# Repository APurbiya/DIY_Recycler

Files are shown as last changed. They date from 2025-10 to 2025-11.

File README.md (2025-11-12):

<p align="center">
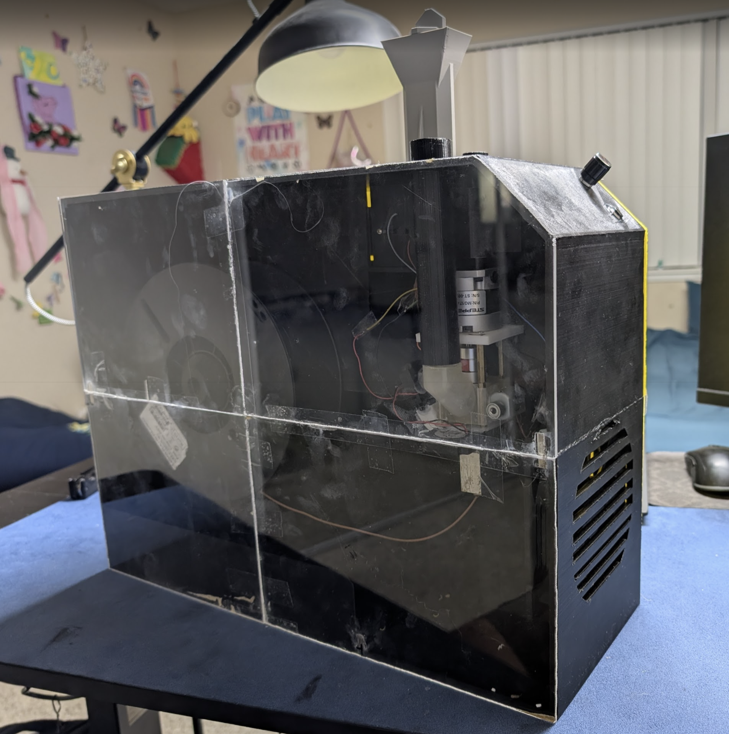
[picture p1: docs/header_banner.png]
Bambu Poop Recycler Banner
  
</p>
# ♻️ Bambu Poop Recycler – Desktop Filament Extruder

Converting **Bambu Poop** (failed prints / support waste) back into **usable filament** using a **screw-based extruder**.  
The goal: a **compact, desktop-friendly recycler** that handles the entire process — **shredding → extruding → spooling** — all from one enclosure.

---

## 📚 Table of Contents

- [🧩 System Overview](#-system-overview)
- [⚡️ Power Distribution](#️-power-distribution)
- [🧵 RAMPS 1.4 Wiring Guide](#-ramps-14-wiring-guide)
- [⚙️ 12 V PSU → Component Wiring](#️-12-v-psu--component-wiring)
- [🪛 Assembly Tips](#-assembly-tips)
- [🧯 Power Safety](#-power-safety)
- [🤖 3D Printing Guide](#-3d-printing-guide)
- [🧰 Assembly](#-assembly)
  - [🔩 Extruder Assembly](#-extruder-assembly)
  - [⚙️ Shredder Assembly](#️-shredder-assembly)
  - [🧱 Main Housing Assembly](#-main-housing-assembly)
  - [🎞️ Spooler Assembly](#-spooler-assembly)
  - [🧩 Final Integration](#-final-integration)

---

## 🧩 System Overview

| Component | Function |
|---|---|
| **Arduino Mega + RAMPS 1.4** | Controls heater, thermistor, fans, vibrator, and 2 stepper drivers (extruder screw + spooler). |
| **Drill Motor + Motor Controller (e.g., DC PWM driver)** | Drives shredder or auger screw for initial granulation. |
| **12 V PSU (≥ 20 A)** | Main power source for heaters, fans, steppers, and motor controller. |
| **Buck Converter (12 V → 5 V)** | Powers ESP32 dashboard and 5 V logic fans. |
| **ESP32** | Monitors Mega’s serial output and serves real-time data on a local webpage. |

---

## ⚡️ Power Distribution

| Source | Destination | Description |
|---|---|---|
| **12 V DC PSU (20 A min)** | **RAMPS 1.4 (11 A + 5 A inputs)** | Main power for heater, fans, and steppers |
|  | **DC Motor Controller (for drill motor)** | Supplies high-current 12 V for shredding/auger motor |
|  | **Buck Converter (input)** | Feeds 12 V into buck regulator |
|  | → **5 V Output (from Buck Converter)** | Powers ESP32 + 5 V logic fans |
| **Ground (GND)** | All components common | Connect PSU GND ↔ RAMPS GND ↔ Buck GND ↔ Motor Controller GND ↔ ESP32 GND |

✅ **Tip:** all grounds **must** be common (PSU GND ↔ RAMPS GND ↔ Buck GND ↔ Motor Controller GND ↔ ESP32 GND).

---

## 🧵 RAMPS 1.4 Wiring Guide

| Function | RAMPS Pins | Connected Component | Notes |
|---|---|---|---|
| **Heater** | D10 | Extruder heater cartridge | MOSFET output, 12 V |
| **Thermistor (T0)** | T0 (A13) | 100 k NTC thermistor | Connect one leg to T0, one to GND |
| **Stepper A (E0)** | X-driver socket (A_STEP=54, A_DIR=55, A_EN=38) | Extruder stepper | Drives screw |
| **Stepper B (E1)** | Y-driver socket (B_STEP=60, B_DIR=61, B_EN=56) | Spooler stepper | Controls filament winding |
| **Fans (12 V)** | D9 (PWM MOSFET) | 12 V cooling fan | Variable speed based on temp/activity |
| **Fans (5 V)** | D4, D6 | Small logic fans | Driven via MOSFET or transistor boards |
| **Vibrator / Mixer Motor** | D16/D17/D5 → L298N IN1/IN2/ENA | Vibrating base / mixer | PWM controlled |
| **Heat Toggle Button** | A15 | Momentary push button → GND | Toggles heating cycle |
| **Encoder** | D31 (CLK), D33 (DT), D35 (SW) | Rotary encoder | Speed + direction control |
| **ESP32 Link** | TX0 (pin 1) → RX (via 1 k/2 k divider) | ESP32 RX pin | Sends data for web dashboard |
| | RX0 (pin 0) ← TX (3.3 V) | ESP32 TX pin | Optional (disconnect when uploading) |

---

## ⚙️ 12 V PSU → Component Wiring

| Output | Destination | Wire Gauge | Notes |
|---|---|---|---|
| +12 V | RAMPS Power Inputs (11 A & 5 A) | 14–16 AWG | Use ferrules or ring terminals |
| +12 V | Drill Motor Controller V+ | 14 AWG | Feeds high-current DC motor |
| +12 V | Buck Converter IN+ | 18 AWG | For ESP32 + 5 V logic |
| GND | Common to all | 14–18 AWG | Must tie all GNDs together |

### Buck Converter
| Input | Output | Use |
|---|---|-----|
| 12 V IN + / – | 5 V OUT + / – | Powers ESP32, small 5 V fans and L298N |

### Drill Motor Controller
| Input | Output | Use |
|---|---|-----|
| +12 V / GND | M+ / M– | Connects to drill/auger motor |
| PWM / POT / CTRL | Optional | Speed control (manual or logic-level) |

---

## 🪛 Assembly Tips

- **Full assembly guide will me added SOON**
- Keep **heater + thermistor wires** away from **motor leads** to avoid noise.
- Mount the **buck converter** near the ESP32; keep its output wires short.
- Label all 12 V lines before final crimping.
- Always test the **heater MOSFET** and **fan MOSFETs** with a multimeter before loading filament.
- Add a **thermal fuse (250 °C)** inline with the heater block for safety.

---

## 🧯 Power Safety

- Use a **12 V 20 A (240 W) PSU** with built-in short-circuit protection.
- Add a **5 A inline fuse** for the RAMPS input and **10 A fuse** for the motor controller branch.
- Ensure metal enclosures are **earth-grounded**.
- Never leave the extruder unattended while heating.

---
## 🤖 3D Printing Guide

- **Extruder**
  - `extruder - chute.step` *(PLA or Resin)*
  - `extruder - pipe.step` *(PLA)*
  - `fan mount - Part 1.step` *(Resin)*
  - `extruder Copy 1 - Part 1.step` *(PLA or Resin)*
  - `extruder Copy 1 - Part 2.step` *(High Temp Resin)*
  - `extruder Copy 1 - Part 3.step` *(High Temp Resin)*

- **Spooler**
  - `main - Spur gear (170 teeth).step` *(PLA)*
  - `main - Spur gear (30 teeth).step` *(PLA)*
  - `spooler - Part 1.step` *(PLA)*

- **Shredder**
  - `spooler - Part 1.step` *(PLA, 4–5 wall loops recommended)*

- **Main (All PLA)**
  - `main - Motor.step`
  - `main - Part 1.step`
  - `main - Part 4.step`
  - `main - Part 6.step` *(1/4 of Part 1)*
  - `main - Part 7.step` *(2/4 of Part 1)*
  - `main - Part 8.step` *(3/4 of Part 1)*
  - `main - Part 9.step` *(4/4 of Part 1)*
  - `main - motor-holder.step` *(for spooler)*

---

## 🧰 Assembly

This section provides a step-by-step **assembly guide for the entire Bambu Poop Recycler**, broken down into key modules — **Extruder**, **Spooler**, **Shredder**, and **Main Frame**.  
Each subsection includes detailed instructions, part references, and visuals to help you build, wire, and align every component of the system.

Before starting:
- Make sure all 3D-printed and mechanical parts are **cleaned, deburred, and test-fitted**.
- Keep **thread locker, M3/M4 hardware**, and a **soldering iron or crimping tools** nearby.
- Follow the wiring and safety guidelines in earlier sections before powering the system.

---

### 🔩 Extruder Assembly

1. **Attach the Stepper Motor and Planetary Gearbox**  
   Grab your **NEMA stepper motor** and **planetary gearbox**.  
   Use **four M3 screws** to fasten them together as shown in the image below.  

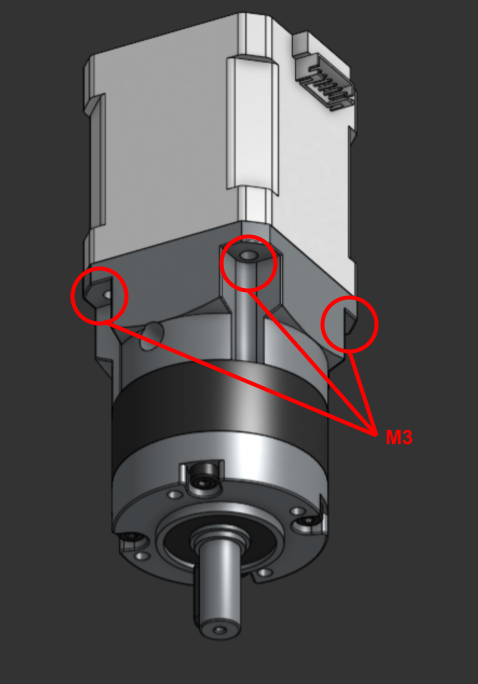
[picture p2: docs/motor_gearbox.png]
Motor + Gearbox Assembly
     
   *Figure 1: Stepper motor and planetary gearbox mounted together.*

---

2. **Mount the 3D-Printed Plate**  
   Secure the **3D-printed plate** to the **planetary gearbox** using **M4 screws** as shown below.  

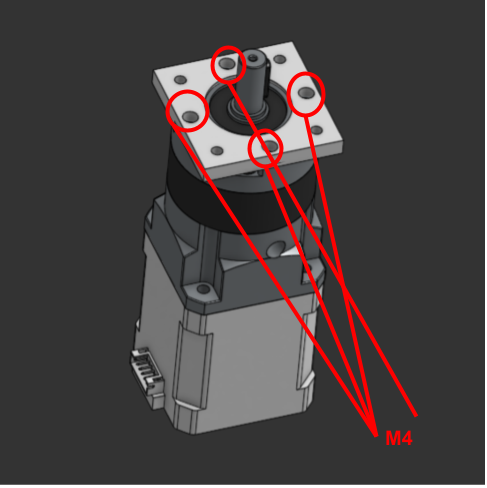
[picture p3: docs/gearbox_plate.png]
Gearbox Mounting Plate
     
   *Figure 2: 3D-printed plate mounted to the gearbox.*

---

3. **Install the Extension Rods**  
   Screw in **four M3 threaded extension rods** (each **57 mm long**) into the plate.  
   Make sure all rods are evenly tightened and parallel.  

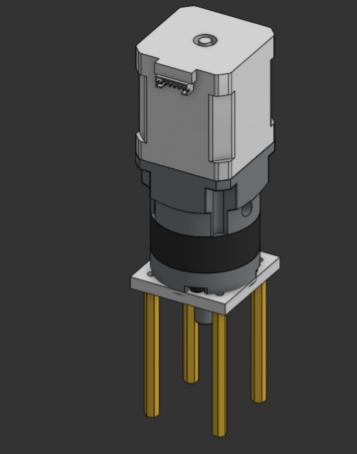
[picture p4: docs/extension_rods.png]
Extension Rods Installation
     
   *Figure 3: Four M4 rods installed on the plate.*

---

4. **Attach the Chute and Resin Plates**  
   Slide the **chute** into the **M3 extension holes** and align it with the bottom side of the assembly.  
   Then attach the **two resin-printed plates** using **M3 screws**.  
   It’s recommended to print these two plates using a **high-temperature material** (e.g., ABS, ASA, or PA-CF).  

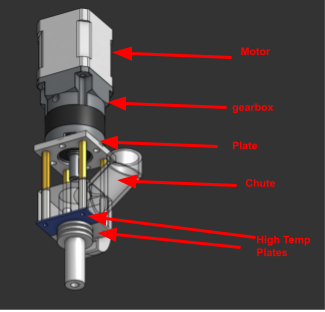
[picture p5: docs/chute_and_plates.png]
Chute and Resin Plates
     
   *Figure 4: Chute inserted and resin plates secured.*

---

5. **Install Cooling and Vibration Components**  
   Hot glue the **fans** and **vent channels** onto the sides of the chute,  
   and attach the **vibration motor** to one side as shown below.  

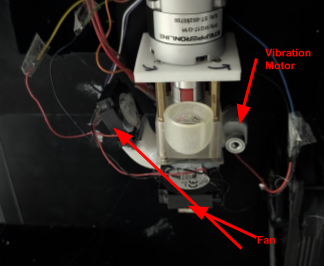
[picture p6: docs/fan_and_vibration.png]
Fans and Vibration Motor Installation
     
   *Figure 5: Fan and vibration motor placement.*

---

6. **Final Extruder Assembly Overview**  
   This is what the completed extruder assembly should look like:  

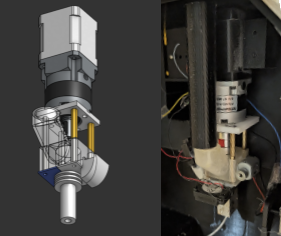
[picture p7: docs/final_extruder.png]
Complete Extruder Assembly
     
   *Figure 6: Final assembled extruder module.*

---

🧠 **Tips:**
- Use **thread locker (Loctite Blue)** on all metal-to-metal threads.
- Ensure the **gearbox output shaft** rotates freely before connecting the screw.
- Keep **fans oriented** to blow across the chute for optimal cooling.
- Route wiring away from the heater and moving parts.

---

### ⚙️ Shredder Assembly

1. **Prepare the Shredder Blade**  
   Cut a **metal ruler** to the correct length so it fits snugly inside the **3D-printed shredder housing**.  
   Make sure both ends are cleanly trimmed and free of burrs before assembly.  

---

2. **Install the Router Bit**  
   Insert the **router bit** into the side hole of the shredder assembly.  
   Slide it in carefully until it seats fully, then **tighten the drill chuck** to secure it in place.  

---

3. **Attach the Motor Mount**  
   Use the **shredder motor mount** to align the drill motor with the printed housing.  
   Do not glue or bolt it permanently yet — this will later **slide into the main frame** during final assembly.  

---

4. **Final Shredder Assembly Overview**  
   The completed shredder module should look similar to the image below.  
   Ensure the **ruler blade**, **router bit**, and **motor mount** all align properly within the printed frame.  

   Final Shredder Assembly  
   *Figure 4: Completed shredder assembly.*

---

🧠 **Tip:**
- Double-check that the **router bit spins freely** without wobble before powering it.   

---

### 🧱 Main Housing Assembly

1. **Align the Printed Sections**  
   Gather all **four 3D-printed housing parts**.  
   Lay them out in order — start with the **top-left section**, followed by the **top-right**, then move **downward** as shown in the reference image.  
   Ensure the edges are clean and fit together tightly before gluing.

---

2. **Bond the Housing Sections**  
   Apply **super glue or CA glue** along the connecting seams.  
   Begin by gluing the **top-left section**, then move to the **right side**, and finally **assemble the lower sections**.  
   Make sure each joint is aligned properly before the glue sets.

---

3. **Final Main Housing Overview**  
   Once assembled, check that the full frame sits flat and square.  
   The **shredder** and **extruder modules** will later slide into this housing frame during final assembly.

   Completed Main Housing  
   *Figure 3: Completed main housing ready for module installation.*

---

🧠 **Tips:**
- Lightly sand the joint surfaces before gluing for stronger adhesion.  
- Use **clamps** or **tape** to hold parts in place while the glue cures.  

---

### 🎞️ Spooler Assembly

1. **Insert the Spur Gear**  
   Take the **large spur gear** and insert it **from the back side of the main housing**.  
   Make sure the gear teeth are facing inward and mesh smoothly with the drive gear inside the housing.  
   Rotate it by hand to confirm it spins freely without binding.
---

2. **Attach the Spooler Module**  
   Align the **spooler part** with the front opening of the housing.  
   Gently **press or clip** it into place — it should hold firmly without glue.  
   If you prefer a more permanent connection, you can add a **small drop of super glue** at each corner.

---

3. **Check Alignment and Rotation**  
   Once installed, ensure the spooler gear and main gear rotate smoothly together.  
   The spool should sit centered and spin freely without wobble.

   Final Spooler Assembly  
   *Figure 3: Completed spooler assembly mounted to the main housing.*

---

🧠 **Tip:**
- If rotation feels stiff, lightly **sand the inner gear edges** or apply a **drop of PTFE lubricant**.  

---

### 🧩 Final Integration

1. **Insert the Shredder Assembly**  
   Slide the **shredder assembly** in **from the back side** of the main housing.  
   Align it carefully with the **top opening** so that the chute and blade section fit into their designated slots.  
   Make sure the motor mount sits flush and the assembly can move slightly for final alignment.

   Insert Shredder Assembly  
   *Figure 1: Shredder assembly slid into position from the back.*

---

2. **Install the Extruder Assembly**  
   Next, slide the **extruder assembly** into the front section of the housing.  
   The **stepper motor** should snap or slide into the **mounting clip** integrated into the frame.  
   Double-check that the extruder chute aligns with the shredder output path for smooth material flow.

   Install Extruder Assembly  
   *Figure 2: Extruder assembly clipped into the front stepper mount.*

---

3. **Verify Module Alignment**  
   With both assemblies in place, check that:
   - The **shredder outlet** aligns directly above the ** hole**.  
   - The **wiring paths** are clear and not pinched between parts.  
   - The **motor shafts** rotate freely without resistance.  

---

🧠 **Tips:** 
- If fitment feels tight, lightly sand the mounting clips or interior guides.  

---

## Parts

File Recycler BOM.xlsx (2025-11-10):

Item | Link | Link 2 | Unit(s) | Unit Price | Total cost
Extruder
Pellet Extruder | https://www.aliexpress.us/item/3256809312197411.html | https://www.amazon.com/Pellet-Extruder-Feeding-Printer-Accessory/dp/B0CF2SF23Q/ | 1 | $87.79 | $87.79
Stepper Motor | https://www.amazon.com/STEPPERONLINE-Stepper-Bipolar-Connector-compatible/dp/B00PNEQKC0 |  | 2 | $13.99 | $27.98 | Total | $337.30
10:1 Reduction | https://www.amazon.com/STEPPERONLINE-STEPPERONLINE-Planetary-Gearbox-Gear-Ratio-5-1-Backlash-30-arc-min-for-9-5mm-Short-Shaft-Length-Nema-17-Stepper-Motor/dp/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 |  | 1 | $24.00 | $24.00
Heater | https://www.amazon.com/ENOMAKER-Ceramic-Cartridge-Thermistor-Creality/dp/B07K2Z3YW4 |  | 1 | $9.45 | $9.45
Nozzel | https://www.amazon.com/Aokin-Extruder-Nozzles-Printer-Filament/dp/B0BLW918YV/ |  | 1 | $5.79 | $5.79
12v fan | https://www.amazon.com/Kingwin-120mm-Silent-Coolers-Mining/dp/B002YFP8BK |  | 1 | $6.69 | $6.69
5v Fan | https://www.amazon.com/Printer-Micro-Brushless-Cooling-Ventilation/dp/B0DY6GQMJX |  | 2 | $3.00 | $5.99
Shredder
Router Bit | https://www.amazon.com/gp/aw/d/B07WW39K4N?psc=1&ref=ppx_pop_mob_b_asin_title |  | 1 | $14.99 | $14.99
drill | https://www.harborfreight.com/12v-cordless-38-in-drill-kit-with-battery-and-charger-57366.html (http://amazon.com/%E2%80%8C12V-775-DC-Motor-Built/dp/B0BW73LMP7) | for shredder | 1 | $19.90 | $19.90
Control Electronics
PSU | https://www.amazon.com/Taormey-Switching-Converter-Transformer-Industrial/dp/B0DP99NVM7/ |  | 1 | $19.39 | $19.39
RAMP 1.4 | https://www.amazon.com/HiLetgo-Control-Printer-Support-Arduino/dp/B06XZ46PDJ |  | 1 | $9.39 | $9.39
Arduino Mega | https://www.amazon.com/ELEGOO-ATmega2560-ATMEGA16U2-Arduino-Compliant/dp/B01H4ZDYCE |  | 1 | $22.99 | $22.99
Buck Converter | https://www.amazon.com/Converter-3-2V-35V-DC1-25V-30V-Voltage-Regulator/dp/B0D7ZWVSFW |  | 1 | $4.99 | $4.99
Motor Driver | https://www.amazon.com/Controller-Driver-Module-Current-Regulator/dp/B075FR2LBP | for shredder | 1 | $10.41 | $10.41
Button | https://www.amazon.com/dp/B0B8Z14K3T/ref=twister_B0CP3QH4PC?_encoding=UTF8&th=1 |  | 2 | $1.60 | $3.20
Rotory Encoder | https://www.amazon.com/WayinTop-Degree-Encoder-Development-Arduino/dp/B07T3672VK?s=industrial |  | 1 | $2.40 | $2.40
Misc
Filament |  | PLA | 1 | $15.00 | $15.00
Resin |  | Something high temp | 1 | $20.00 | $20.00
M4 Button Head | https://www.amazon.com/BinifiMux-Phillips-Countersunk-Assortment-Repairing/dp/B07S18NHP5?s=industrial | Gearbox to Stepper motor | 1 | $6.99 | $6.99
M3 Screws | https://www.amazon.com/710PCS-Assortment-Metric-Washers-Printing/dp/B0F3JKMZLN?s=industrial |  | 1 | $7.98 | $7.98
Aluminum Spacer Posts M3 | https://www.amazon.com/Threaded-Aluminum-Spacers-Quadcopters-Fasteners/dp/B0CL4DW2JX | Extruder Assembly | 2 | $5.99 | $11.98

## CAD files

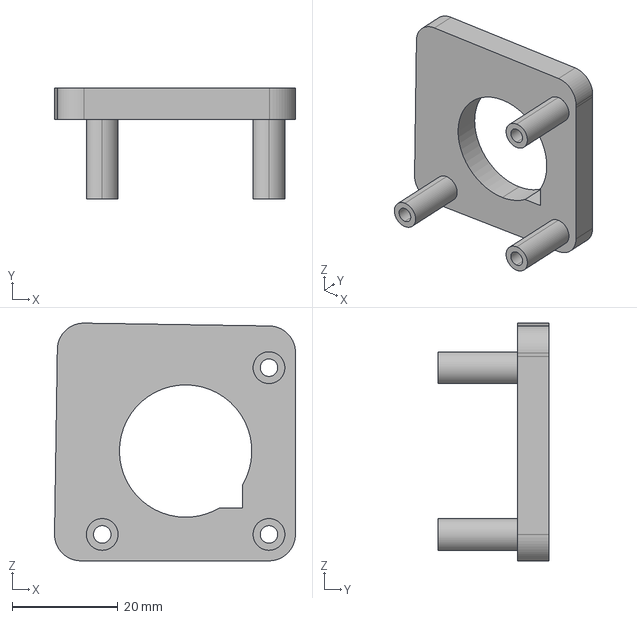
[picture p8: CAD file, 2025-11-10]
CAD/Main/main - motor-holder.step
45.5 x 21.0 x 44.9 mm

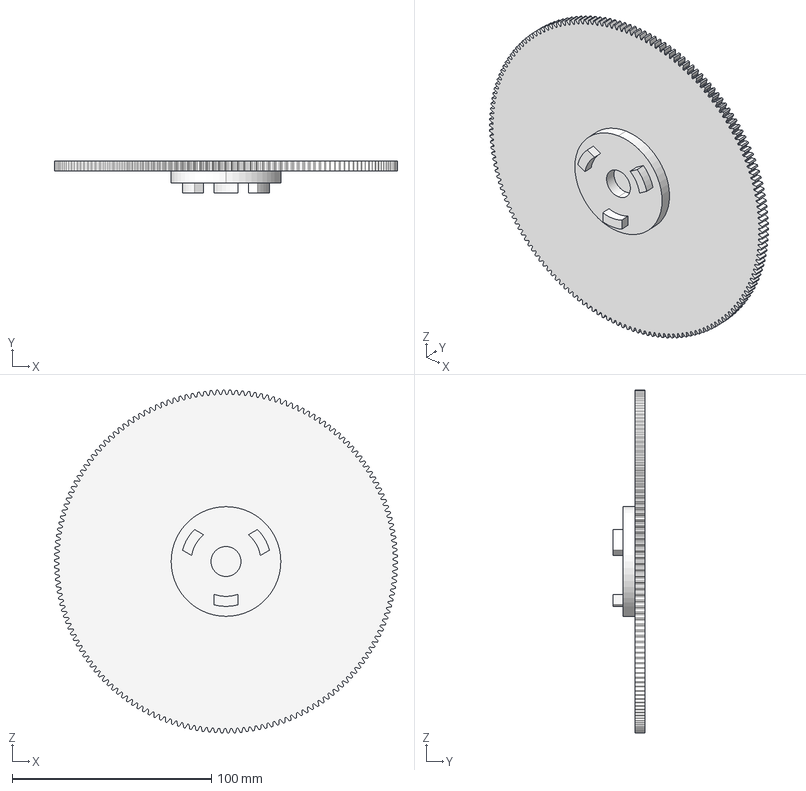
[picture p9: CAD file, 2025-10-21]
CAD/Spooler/main - Spur gear (170 teeth).step
172.0 x 16.0 x 172.0 mm

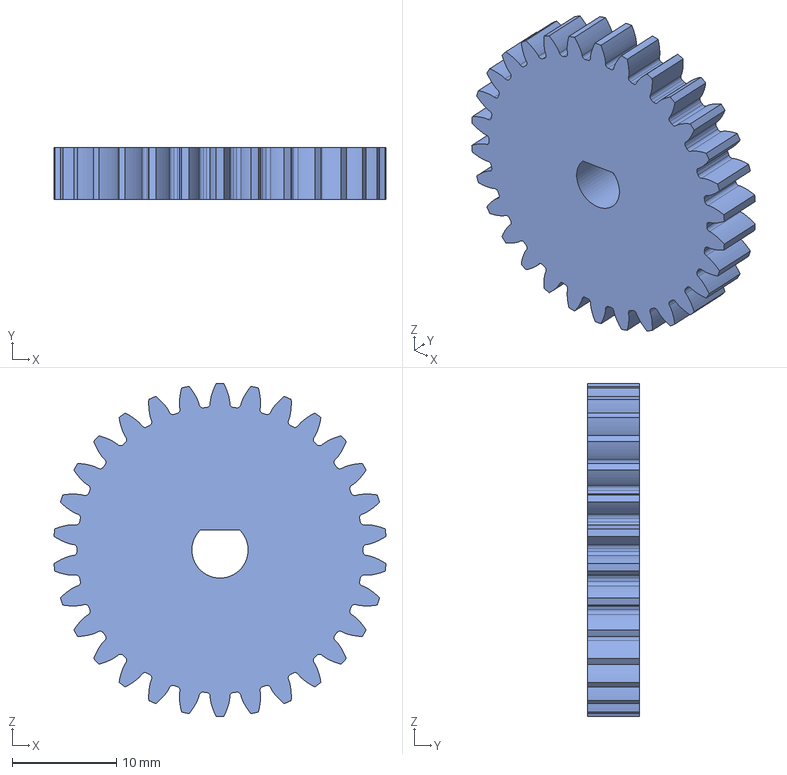
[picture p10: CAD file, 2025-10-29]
CAD/Main/main - Spur gear (30 teeth).step
31.9 x 5.00 x 32.0 mm

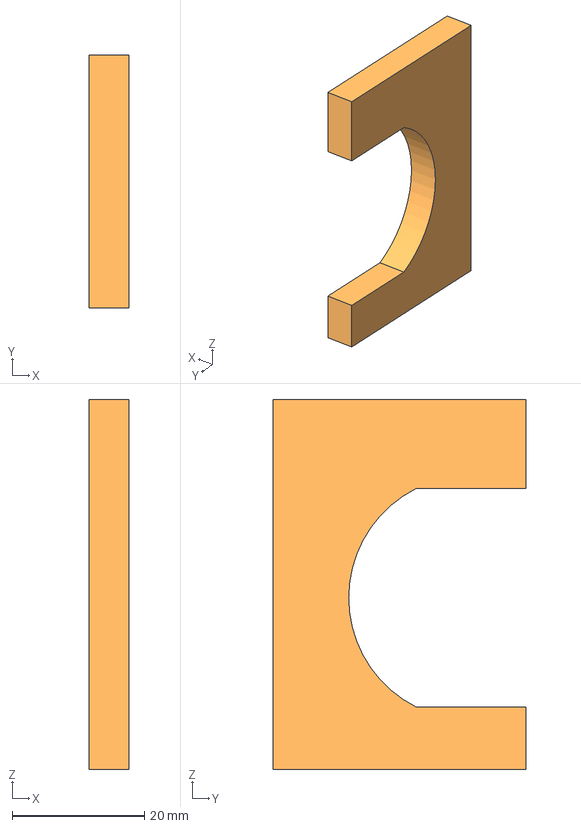
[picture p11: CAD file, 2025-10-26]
CAD/Main/main - Motor.step
6.00 x 38.4 x 56.0 mm

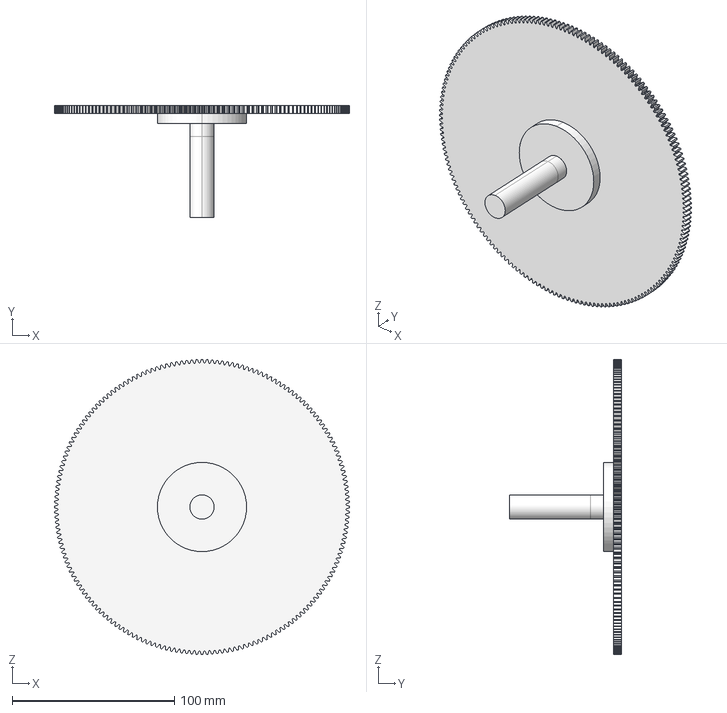
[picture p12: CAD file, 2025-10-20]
CAD/Spooler/main - Spur gear (180 teeth).step
182.0 x 69.0 x 182.0 mm

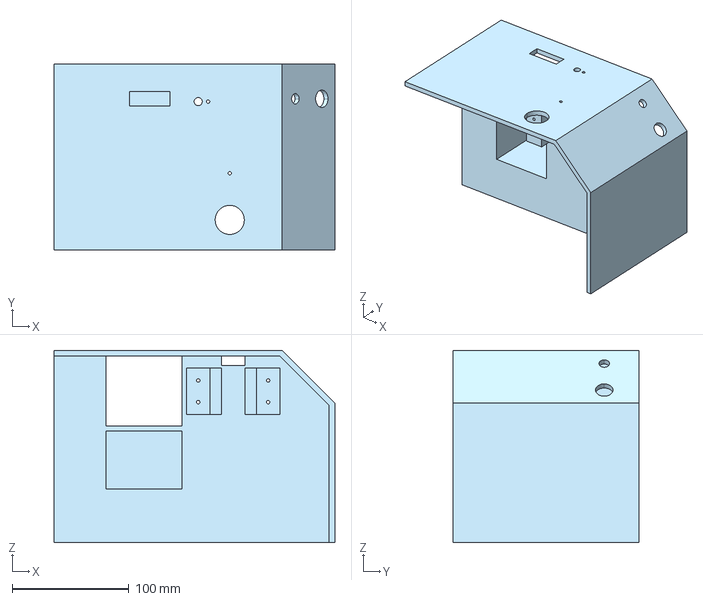
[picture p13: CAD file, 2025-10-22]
CAD/Main/main - Part 7.step
241.2 x 160.0 x 165.0 mm

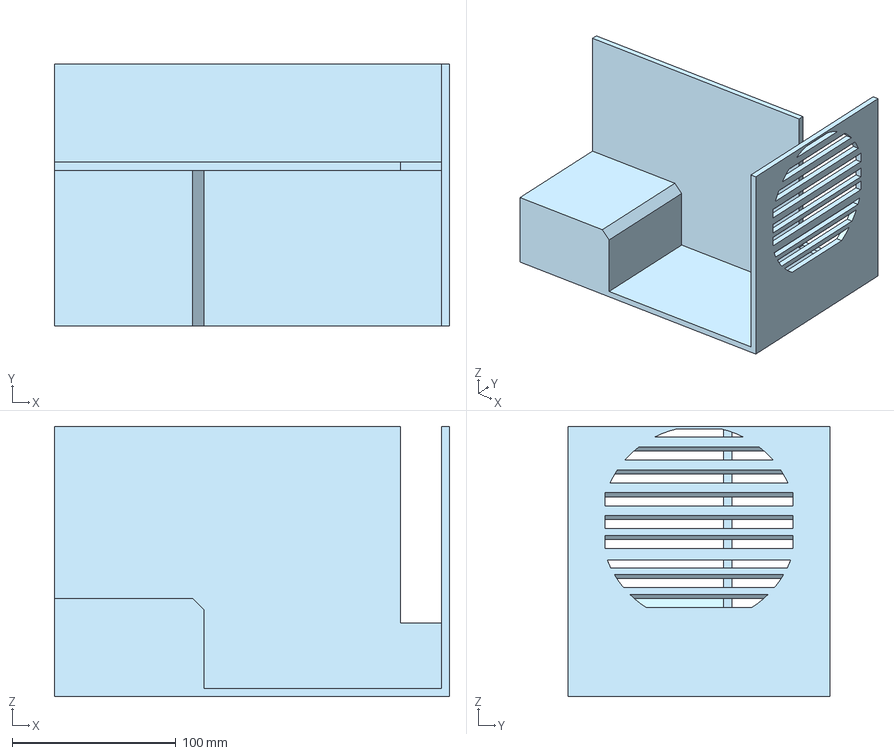
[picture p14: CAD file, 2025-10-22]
CAD/Main/main - Part 6.step
241.2 x 160.0 x 165.0 mm

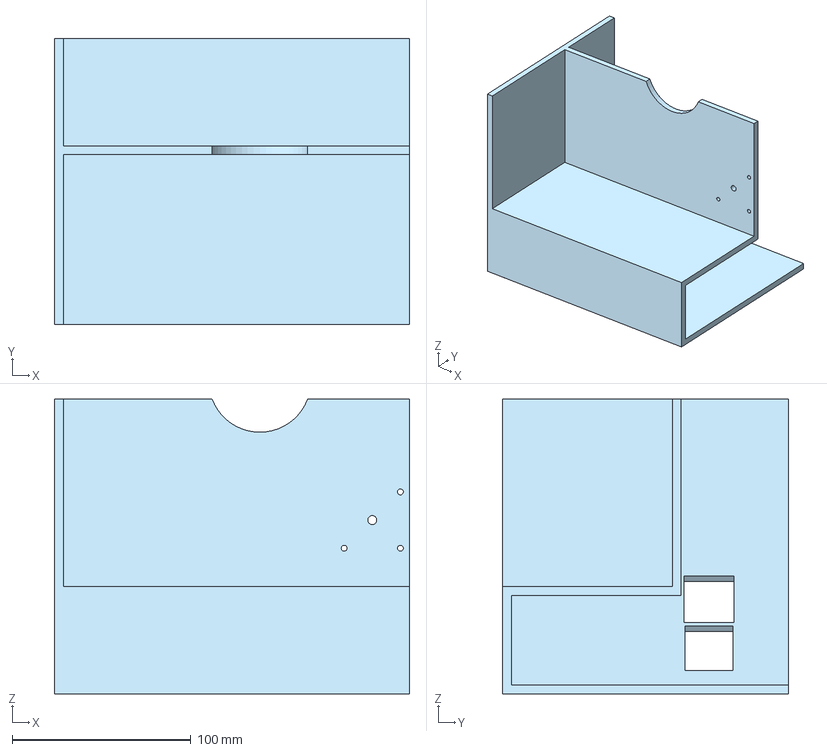
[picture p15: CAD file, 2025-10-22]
CAD/Main/main - Part 9.step
198.8 x 160.0 x 165.0 mm

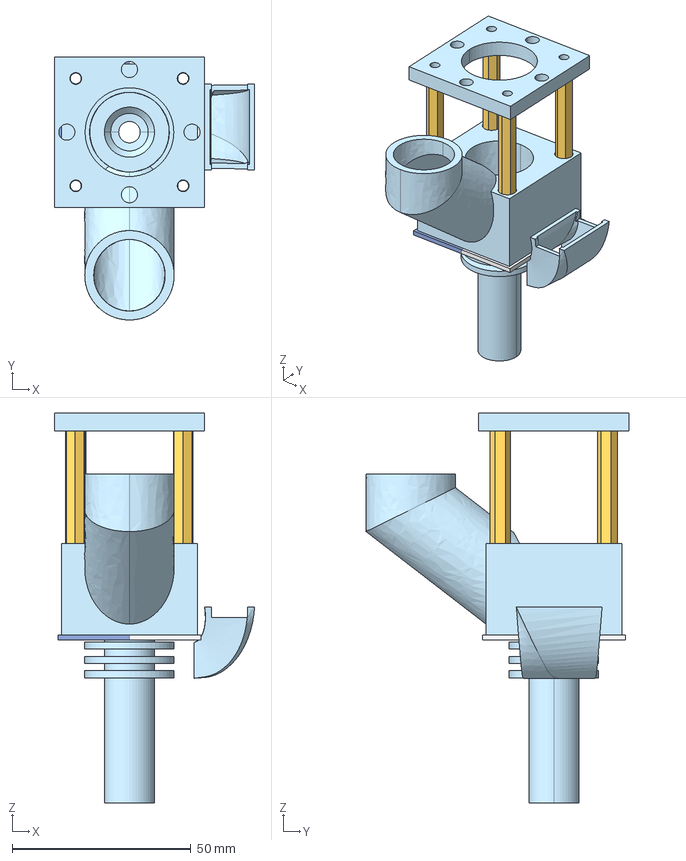
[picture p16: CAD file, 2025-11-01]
CAD/Extruder/extruder-assembly.step
56.0 x 73.5 x 109.0 mm
m3-standoff x 4
heating-chamber
chute

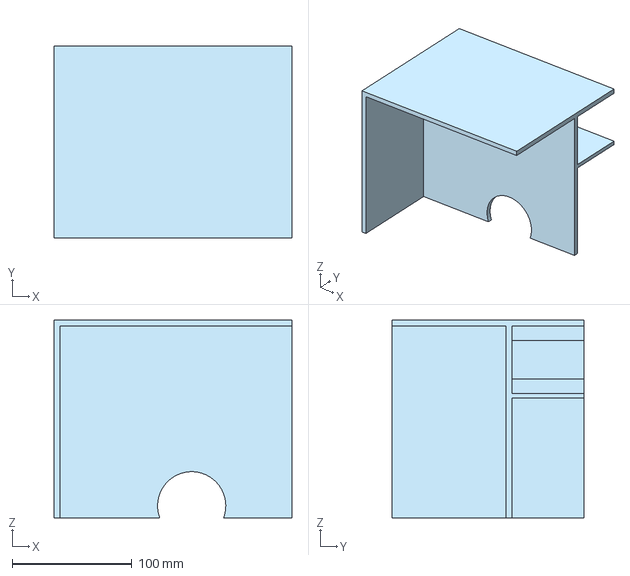
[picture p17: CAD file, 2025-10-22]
CAD/Main/main - Part 8.step
198.8 x 160.0 x 165.0 mm

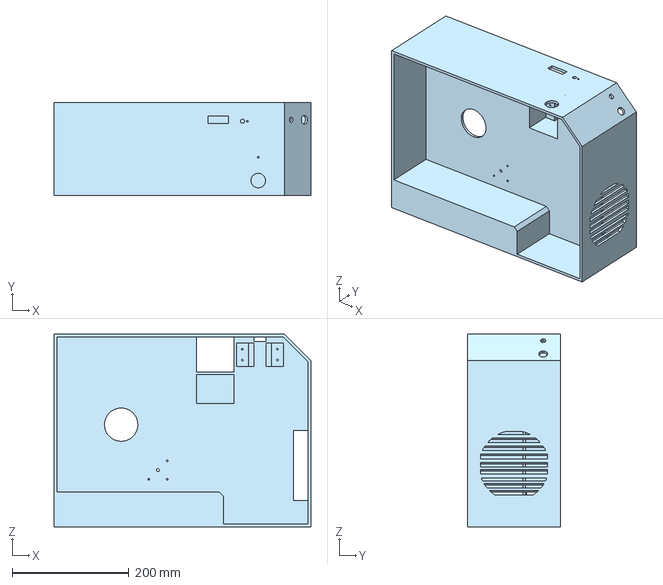
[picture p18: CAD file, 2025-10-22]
CAD/Main/main - Part 1.step
440.0 x 160.0 x 330.0 mm

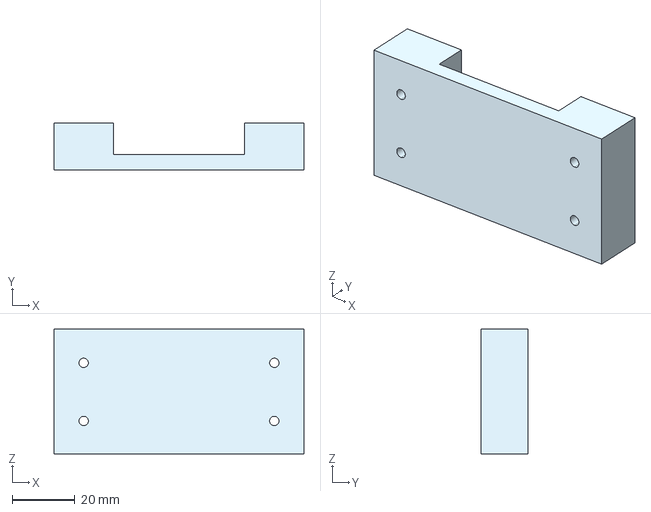
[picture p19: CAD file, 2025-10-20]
CAD/Main/main - Part 4.step
80.0 x 15.0 x 40.0 mm

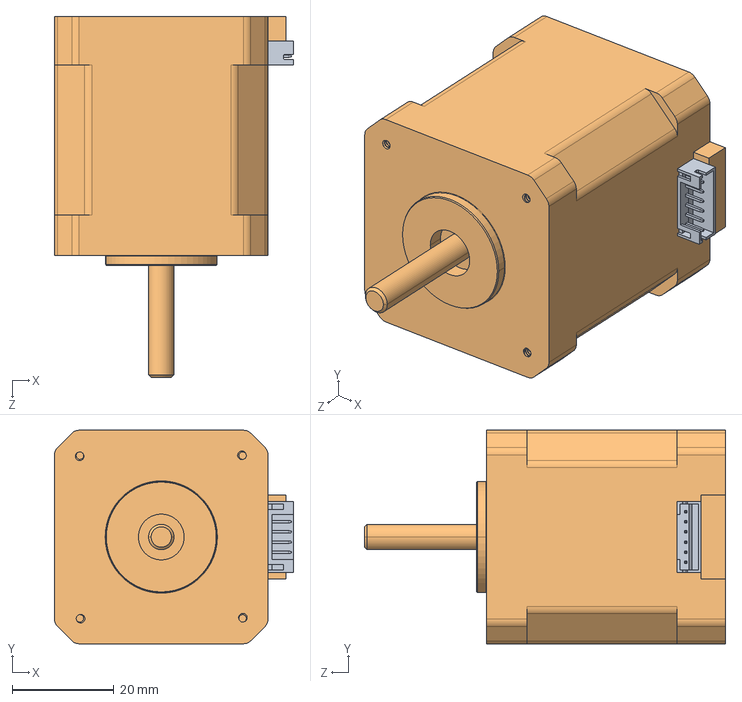
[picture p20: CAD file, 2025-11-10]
CAD/CAD Imports/Stepper motor SUPER POWER.STEP
47.0 x 42.0 x 71.0 mm

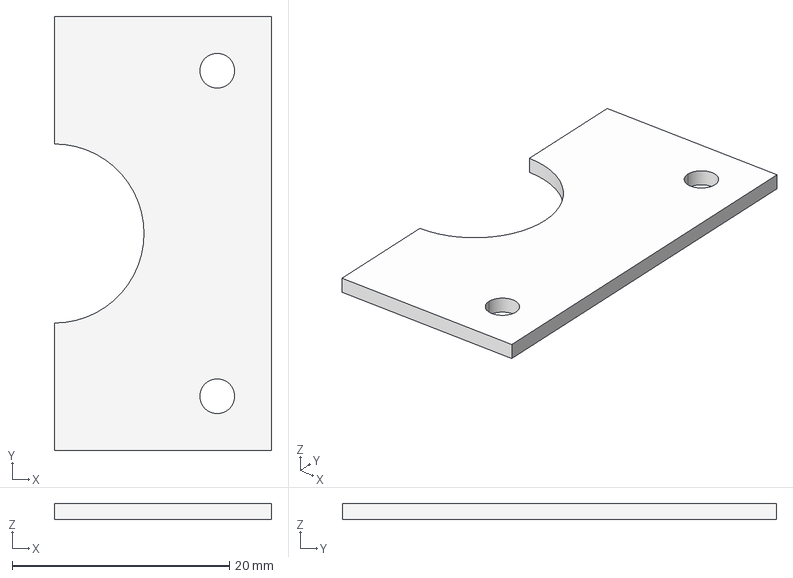
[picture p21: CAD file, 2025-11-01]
CAD/Extruder/extruder Copy 1 - Part 4.step
20.0 x 40.0 x 1.50 mm

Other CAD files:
CAD/Spooler/main - Spur gear (30 teeth).step
CAD/Laser-sketchs/panels - back-panel.step
CAD/Shreder/Shredder - p1.step
CAD/CAD Imports/HLTNC FLE42-LSW.stp
CAD/Extruder/extruder - chute.step
CAD/Extruder/extruder - pipe.step
CAD/Extruder/extruder Copy 1 - Part 1.step
CAD/Extruder/extruder Copy 1 - Part 2.step
CAD/Extruder/extruder Copy 1 - Part 3.step
CAD/Extruder/extruder#1 - heating-chamber.step
CAD/Extruder/extruder#1 - m3-standoff.step
CAD/Extruder/fan mount - Part 1.step
CAD/Laser-sketchs/Part Studio 3 - bottom-left.dxf
CAD/Laser-sketchs/Part Studio 3 - bottom-right.dxf
CAD/Laser-sketchs/Part Studio 3 - top-left.dxf
CAD/Laser-sketchs/Part Studio 3 - top-right.dxf
CAD/Laser-sketchs/panels - front-panel.step
CAD/Spooler/spooler - Part 1.step

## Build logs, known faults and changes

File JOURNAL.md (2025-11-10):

<!--
  ===================    !!READ THIS NOTICE!!   ====================
  DO NOT edit this file manually. Your changes WILL BE OVERWRITTEN!
  This journal is auto generated and updated by Hack Club Blueprint.
  To edit this file, please edit your journal entries on Blueprint.
  ==================================================================
-->

## 10/17/2025 1 PM - Drawing Rought Sketches   

I started brainstroming ideas and sketched out some ideas of how everything can be positioned. I had to think about overall size as I want to keep it kinda small. Next I am going to look of some of the parts and start sketching it in Onshape. I also need to see if a motor can power a mini shreder. I also need to run 2 stepper motors one from extruder and spooler. I am thinking of using the RAMPS 1.4 board. I looked into all the power requierments but I need to find a good power supply

## 10/17/2025 5 PM - Researched Parts & Created a List  

I did a lot of research looking to see if anyone had already done something like this before or any parts or components I can find. I did not see anything promising so I created a list of parts I think I will need. I am most likely going to change parts as I get more and more into the project but for now this it it. I also went on printables where I found a pelitizer model which gave me an idea for the shredder and why I have a router bit in my BOM. I already have some of the parts but I have ordered all the other parts and they should  come in a a week untill then I am most likly going to work on cad. 

## 10/17/2025 7 PM - Started Working on CAD Sketch  

I hoped into onshape and started working on the CAD sketch, I took what I drew out and then make a rought sketch after which I had to go to many different product pages to get dimentions of the different items I want to use and dimention that in. This all tool a long time because I wanted to dimention everything as accuratly as I can so its easier for me later down the line. The angle on the side is where I would want to mount the button and stuff, still need to figure out how the shredder will work.

https://cad.onshape.com/documents/801ecd6329a45d18a34da95f/w/21c4afe4d5408c28a9ff9146/e/d5dffae5cc0ec32277c5b998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



## 10/18/2025 8 AM - Added Items to BOM  

I changed the formatting of the BOM today and added two items that I forgot yeaterday. I ordered the new parts so they should arrive soon as well. The parts I ordered yeaterday should also com ebefore the end of the weekend and that will help me spped up my cad work. I am going to finish the sketch later today. I am not sure if the 775 stepper motor will get the job done but I hope it does, I might have to gear it maybe 5:1 or maybe even more.



## 10/18/2025 10 AM - Shredder CAD  

I started working on the CAD for a shredder, I wanted it to be able to crush down Bambu poop down to a size where it could be run through a pelet extruder. I came accross this model https://www.printables.com/model/738194-micro-plastic-shredder I liked it but it was missing a few things I wanted so I based my model off that one  I added a mount for a 775 motor and a 5:1 gear ratio to test it. I was also able to get the model sliced and off to my printers to print. I want to make sure the shredder works before working on the CAD for the main frame just incase I need to try something different, you can find the cad on onshape and I will uplooad the step files on Github as well.

https://cad.onshape.com/documents/801ecd6329a45d18a34da95f/w/21c4afe4d5408c28a9ff9146/e/d5dffae5cc0ec32277c5b998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  

## 10/18/2025 2 PM - Main Body CAD  

I had the sketch from earlier that I used to make this main body, I had to change a few things in order for all the parts to fit. I might have to go back and make more changes as I don't have all the parts and dimentions may not be what they advertize in the images 


This is what I have so far, I like the overall shape. I had a hard time with some of the component place ments so I just made a masive back place where I can mount the ramps board and other parts



It took a lot of back and forth to get all components to fit in a small form factor.



I also started an assembly where I will be adding all the parts as I design them

https://cad.onshape.com/documents/801ecd6329a45d18a34da95f/w/21c4afe4d5408c28a9ff9146/e/d5dffae5cc0ec32277c5b998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

## 10/18/2025 5 PM - Shredder Assembly   

I got the shredder prints all cleaned up and put the assembly together and conencted it to a motor driver to test if this would work. It turns! But when I put poop in there it just stalled under the load. So the 5:1 gear ratio is not going to work going any more that that and the project just gets huge so I found and ordered a cheap 20 buck drill from harbor freight lets see if that works. I put in a some work cleaning the gears as I printed them in resin but it was all for nothing :(





## 10/18/2025 8 PM - Extruder CAD  

I just worked on the CAD for the extruder, and I know right now it dose not look like much because I did not add the motor or the heat block or pipe. But when I do the assembly tomorrow I promise it will all make sense. I had to model some plates that would screw in with some M3 double pass spacers, a fan duct to aim the air flow where I want it and then the pellet duct to get the pellets to the screw.

This is the stack of plates


This is for the fan


And this if for the pellets


I had a hard time with all the lofts as it was hard to get all the profiles and faces just right. I also sliced it and started the print. I will assembel everything tomorrow morning.

https://cad.onshape.com/documents/801ecd6329a45d18a34da95f/w/21c4afe4d5408c28a9ff9146/e/d5dffae5cc0ec32277c5b998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

## 10/19/2025 10 AM - Extruder Assembly  

This morning I started of my cleaning all the prints but washing and then curing them

After that I crimped the stepper motor wiers and screwed in the gearbox


And then I got rest of the parts assembeled and then made a wire harness for the fans and the temp sensor, I soldered one side of it and crimped the other side. Dupont is not easy to crimp :(

I glued the fans on and put everything together. I had to do the crimp a few times as I did not get it right the first time.

Now most of the extruder is = together just need to do some cabel management and then test the heating and motor later today





## 10/19/2025 12 PM - Test Code RAMPS 1.4  

Since I had most of the extruder parts wired up I started writing the code for the arduino mega and the RAMPS 1.4 board. I had to look at a lot of documentation and it took me a while to get all the pin numbers and some context on how to use this board. For right now all the code dose is heat up the extruder to 300 deg C and run the fans but I realized when I plug the 5v fans into the 5v on the ramps it messes with the temp data so I think I am going to have to power them seperatly and have a relay or something similar.

The code also prints out the temp so I can see it while testing. I also tested is the motor spins which it does but I turned it off to test the heating. I am going to add a button and rotary encoder later to control speed and tuff

I also had to de solder a diode on the board in order to power it. This took a really long time as the board is so packed that I didn't want to burn any of the other components around the diode



The code is on the github with better formating :)
`
// ----- RAMPS E0 stepper pins (kept, but motor won't spin) -----
#define A_STEP_PIN    54   // E0 STEP
#define A_DIR_PIN     55   // E0 DIR
#define A_ENABLE_PIN  38   // E0 ENABLE

// ----- Heater & sensor -----
#define HEATER_PIN     10      // D10 = E0 heater MOSFET gate on RAMPS
#define THERMISTOR_PIN A13     // RAMPS T0 (your probe -> GND + A13)

// ----- Fans (must drive via MOSFET/transistor!) -----
#define FAN1_PIN 4            // your 5V fan #1 (via small MOSFET)
#define FAN2_PIN 5            // your 5V fan #2 (via small MOSFET)
#define FAN12_PWM_PIN 9       // RAMPS D9 12V fan MOSFET (PWM-capable)

// ----- Temp window (edit these) -----
float EXTRUDER_MIN_C = 250.0f;   // start heating below this
float EXTRUDER_MAX_C = 280.0f;   // stop heating at/above this

// ----- Thermistor model (100k NTC, B=3950, 4.7k pull-up on RAMPS) -----
const float R_SERIES   = 4700.0f;
const float R0         = 100000.0f;
const float T0_K       = 273.15f + 25.0f;
const float BETA       = 3950.0f;

// ----- Safety limits -----
const float MAX_SAFE_C = 300.0f;
const unsigned long READ_INTERVAL_MS = 200;

// ----- Control flags -----
const bool RUN_STEPPER_TEST = false;

// housekeeping
unsigned long lastReadMs = 0;
bool heaterOn = false;

// --- helper: read thermistor (Celsius) using Beta model ---
float readThermistorC() {
  int a = analogRead(THERMISTOR_PIN);
  if (a <= 1)   return -9999.0f;
  if (a >= 1022) return 9999.0f;
  float Rt = R_SERIES * ( (float)a / (1023.0f - (float)a) );
  float invT = (1.0f / T0_K) + (1.0f / BETA) * log(Rt / R0);
  float Tk = 1.0f / invT;
  return Tk - 273.15f;
}

// --- optional stepper test (kept, not run) ---
void stepperSpinTest() {
  digitalWrite(A_DIR_PIN, HIGH);
  for (int i = 0; i < 80000; i++) {
    digitalWrite(A_STEP_PIN, HIGH); delayMicroseconds(20);
    digitalWrite(A_STEP_PIN, LOW);  delayMicroseconds(20);
  }
  delay(1000);
  digitalWrite(A_DIR_PIN, LOW);
  for (int i = 0; i < 2000; i++) {
    digitalWrite(A_STEP_PIN, HIGH); delayMicroseconds(500);
    digitalWrite(A_STEP_PIN, LOW);  delayMicroseconds(500);
  }
  delay(1000);
}

void setup() {
  // Stepper pins (kept)
  pinMode(A_STEP_PIN,   OUTPUT);
  pinMode(A_DIR_PIN,    OUTPUT);
  pinMode(A_ENABLE_PIN, OUTPUT);
  digitalWrite(A_ENABLE_PIN, HIGH);   // disable driver

  // Heater & fans
  pinMode(HEATER_PIN, OUTPUT);
  digitalWrite(HEATER_PIN, LOW);

  pinMode(FAN1_PIN, OUTPUT);
  pinMode(FAN2_PIN, OUTPUT);
  digitalWrite(FAN1_PIN, LOW);
  digitalWrite(FAN2_PIN, LOW);

  pinMode(FAN12_PWM_PIN, OUTPUT);
  analogWrite(FAN12_PWM_PIN, 0);      // off at start

  // Thermistor
  analogReference(DEFAULT);
  delay(50);
  lastReadMs = millis();

  Serial.begin(115200);
  Serial.println("Extruder heater + fans test ready.");
}

void loop() {
  if (RUN_STEPPER_TEST) {
    digitalWrite(A_ENABLE_PIN, LOW);
    stepperSpinTest();
  } else {
    digitalWrite(A_ENABLE_PIN, HIGH);
  }

  unsigned long now = millis();
  if (now - lastReadMs >= READ_INTERVAL_MS) {
    lastReadMs = now;

    float tc = readThermistorC();

    if (tc > MAX_SAFE_C || tc == 9999.0f || tc == -9999.0f) {
      heaterOn = false;
    } else {
      if (tc < EXTRUDER_MIN_C)       heaterOn = true;
      else if (tc >= EXTRUDER_MAX_C) heaterOn = false;
    }

    // apply outputs
    digitalWrite(HEATER_PIN, heaterOn ? HIGH : LOW);
    digitalWrite(FAN1_PIN,   heaterOn ? HIGH : LOW);
    digitalWrite(FAN2_PIN,   heaterOn ? HIGH : LOW);

    // 12V fan on D9 at ~50% whenever heating (128/255 ≈ 50%)
    analogWrite(FAN12_PWM_PIN, heaterOn ? 128 : 0);

    Serial.print("T(C)="); Serial.print(tc);
    Serial.print("  Heater="); Serial.print(heaterOn ? "ON" : "OFF");
    Serial.print("  D9 PWM="); Serial.println(heaterOn ? 128 : 0);
  }
  delay(2);
}
`

## 10/19/2025 2 PM - Main Body CAD V2  

Last time I worked on main body CAD I designed it so the shredder would be powered by a 775 motor but since that doesn't work I had to change the CAD to fit a drill motor and gear box. This was very hard to do as I basicaly has to start over and because I don't have the drill I bought yet I had to guess the dimentions so I will probably have to change it again in a few days when I get it. I also added a slot for the power cord and a power switch in the back. 





I also have to cut out vent holes for the fan and do some more stuff, but I am taking a break from CAD for a bit

## 10/19/2025 7 PM - More CAAAAD  

I know I said I am not doing CAD anymore but I wanted to get some more work done. Here is what I got done. Created the gears for the spooler system, also made the mount which kinda works like the AMS lite mount. Made the fan vent and then resized the shredder part to maybe fit and drill and the shredder, I also made the holes for the stepper motor mount of the extruder and the cover plate for that.









All cad is on onshape for now, I will put it on Git Hub when I get some more work done and it looks better.

https://cad.onshape.com/documents/801ecd6329a45d18a34da95f/w/21c4afe4d5408c28a9ff9146/e/d5dffae5cc0ec32277c5b998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

## 10/20/2025 5 PM - Some CAD and assembly  

Got a lott of work done today, started the day with printing and cleaning up a print to replace one of the extruder plates that was cracking, the print was 6 mins but then cleaning curing took a while.




then in the afternoon I worked on cad I did some of the math to figure out where the pellet pipe would go and then designed the pipe and added that all to the assembly


I also had to clean up some of the files, and then I organized the git hub repo so all the cad files are in order.

Then I assembeled the plates that I printed in the morning onto the extruder, I also had to glue the 2 fans back on. I used like 10x the hot glue I used the first time to make sure it stays stuck this time.

I am very close to start printing all the parts, the drill arrives tomorrow. I am going to take it apart for the motor then I will make the changes in the CAD for the drill and then slice to start the prints.

this is what the final extruder looks as of right now



## 10/20/2025 9 PM - Spooler CAD  

I have been worrying less about the spooler untilll now... I finalized the gear ratio I will be using for the spooler to work with a stepper motor the ratio I am planing on using is 170:30. The really big gear needs to attach to a part that can allow a spool to be slotted in which I designed previously. I was planing on printing a rod on the gear and the sliding it on but the rod would be week due to direction of layer lines so I re-did that to have a sort of slot and I am going to glue it in place now.

This is what the gear looks like


and then the AMS lite coupler


I had to firsly do a lot of research to figure out how large the gear ratio needs to be in order for me to get enough power. But once I got that the rest seemed okay. I have to now add this to the list of things I need to print. Before the 170teeth gear I had done 180 based on rough math but I realized that was too big almost 18cm across. 

## 10/21/2025 - Shredder Assembly Test and CAD  

The drill arrived, so I started by taking it all apart for its motor and gearbox system, this is causr my original idea with that 775 and the 5:1 gear ratio did not work. Once I took the drill appart I and to de-solder the motor because I did not want to use that control cuircetry.


After that I attached my router bit to the drill and connected the wiers from a 12v psu and the motor controler. After which I started slowly testing if this could shred stuff which it could. While testing this is what my table looked like



Since this set up was able to do its job, I moved on to the longer part of fixing all the CAD to get everything ready for printing. I made a slot in the back for the motor and gearbox, made the slot in the top for the shredder and cleaned up all the dimentions 

 


The hardest part in all of this was holding the drill down while testing, becuase the motor body would just spining if I didn't hold it down right thats why the slot in the back is cut out spcificaly to hold the motor

https://cad.onshape.com/documents/801ecd6329a45d18a34da95f/w/21c4afe4d5408c28a9ff9146/e/9421cdad7b2ed0ff19b5ca85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

## 10/22/2025 - Slpit, SLiced, and Printing  

I stated by cutting the main body cad into parts that could be fit on the build plate of the printers at my school. I also had to see what way to split would affect the least amount of featurs. This is how I split it up


Then I opened up cura and then one by one sliced up all the parts, this is when I reallized in there default orientation it would take lot of supports and 30h per part, so I started messing with orientation. Once I was happy with all of this the saved all of the files. At this point each print would take 24 hour :( 

Then at school I got the printers set up by trying spools thta had been dryed over night and calibrating the print cores of the ultimaker s5 (there were 2 printers)

Then I started the print and checked to make sure the first layer was coming down okay.





When I went back to check after an hour I realized the nozzel got clogged cause this is what I saw


So I used the neddel first then did a few cold pulls to solve this and then started the print again. 

6 hours into the print I realized something about that cad

This part the holds the motor in place should have been a seperate part and I should screw it in so I can adjust where it needs to be. 

So the new plan is to let the print finish and then I will just cut the current part out if it doesn't work  and print just the part and then screw it in.



## 10/23/2025 - 2/4 prints done!  

I had stated the prints yesterday and today 2 of them were done (kinda) on of the printers tripped the breaker with only 2 hours left but the other print turned out well.



So I measure upto the part that worked re sliced only the falied part and then started that print, once that was done I took it off removed a lot of supports. This was probably the hardest part. At one point I had to pour hot water into the part to melt the supports out. Once I got all of that done I sanded all the edges that needed to be glued first with 320 grit to flatten and then with 220 to score it a little for the glue to work. Then I used medium CA glue to stick the 3 parts toether. 

I also got the other 2 prints started so I should have them by tomorrow.

## 10/24/2025 7 AM - Some more print clean up  

I printed 2 more parts that I am going to need in order to put everything together. I printed these in resin so the clean up and post processing to longer. I had already done the cad so all had to do was slices, and then when the print was done some clean up.

Now I have almost all the parts I need to put everything together

Screenshot 2025-10-23 210219.png

Screenshot 2025-10-23 210344.png

## 10/24/2025 4 PM - 4/4 Prints Done!  

The last 2 of the big parts were done printing, I started by getting them off the build plate and then washing both the build plates with soap and water I had put soo much glue that I had to scrape form of the glue off, then I started removing the supports, these 2 had the hardest supports because of the psu slot it was a really large 90 deg overhang. Once I got all the supports off I spent some time sanding all the surfaces that were going to get glued, I went from 320 to 220 on these parts as well. There was a small defect in the first 2 prints so I had to sand extra hard because other wise the parts didn't line up. Screenshot 2025-10-24 161219.png
Screenshot 2025-10-24 161229.png
Screenshot 2025-10-24 161240.png

This is the final result, I am ready to start placing all the components in. I still need to print a few components but other than that we are making good progress.


## 10/25/2025 12 PM - Assembling Components  

Since I had the main frame all printed I started getting all the components in there clued up. I started with the psu the plug and the switch. Soldering these wiers were a pain becuase of the angle. the wire fell out like 5-6 times. I wanted to make sure that wire would not fall out cause what was the AC power.  Then I started glueing all the compontents and the fan to see how best I could fit everything. I also got the rotory encoder screwed in from the outside for the shredder and the button. I also glued a came for the arduino mega date came extention. After I glued all of that I sliced and stated printing some more parts that I am going to need for the next steps!
Just as I was writing this journal I realized I messed up if you look care fully you will see the arduino mega is glued in exactly where the stepper motor is going to get screwed in. So now I need to figure out a new placement for everything.



## 10/25/2025 4 PM - Extruder Assembly V3    

While I was installing the extruder I riped one of the fans off, and I need to replace the chute as well. Luckly I had the new shorter one printed already, so I started by removing the prints and cleaning them off. The chute was easy the shredder part which was on the same build plate was a pain because I had to drain all the resin out from inside by flushing it with some IPA. But after that was all done I cured and the started un screwing the extruder to replace the chute, after than I put most of it back together and got the both the fans hot glued back on. I also added a dc motor with a off set screw to act like a vibrator to help avoid clogs in the chute. I put everything back together. I was trying to get the extention pipe on when I realized the hole in my 3d printed case what not big enough. I hand sanded the hole until it was big enought. That was all I got done. Next I need to fix the electronics on the back





## 10/25/2025 7 PM - Rear Component Placement fixed!  

I had glued the ramps 1.4 board and the buck converter to the back before but had messed up and glued them where the stepper motor was supposed to go. So I spent time removing the components, I was scared about this because I did not want to break the PCB but I had to get the parts off. Once I got them off I figured out new placement and triple checked everything before gluing it down. After the hotglue set I got all the power wires routed and connected. While going so I broke the solder on the switch that I had solded 5 times before already so I got some extra flux scrached the surface of the switch prong then going into that akward spot with a soldering iron I got it togeether.
Now all componets have power


## 10/26/2025 10 AM - Shredder + Motor Assembeled  

Yesterday I had cleaned up the shredder print so today I started getting it put into the main frame. I started by curring the ruler with the dremel so it is the correct length to go into the print. I got the drill gear box screwed in and then I could slide the whole thing in. This is when I realized that the print had not tolerance so I had to sand the thing untill it fit. This took really long since I had cured the resin. I also had to solder longer wiers to the motor but they wern't long enough so I solder some more wier to that. After it fit in I noticed I might have made a small mistake with the motor mounnt. It does not go all the way to the top so I think the motor might spin. While I was pack there I also glued in 2 relays, one of them was just a relay module the other one I had to custom make by looking up the scematics there was no clear way to do this so it took a lot of research and talking to Chat GPT. But I got it done. Next I am going to test the shredder with some poop.





## 10/26/2025 1 PM - I popped a fuse :(  

While testing the shredder, I put some of the filamanet scraps in the top and turned on the motor that all got scredded fine, but then I increased the speed and put some more, this is when the motor came out of the mount and started spinning the body and the fuse on the motor controler popped. I found and order some replacements but now in the mean time I need to do some more cad work to fix all this. I has to untangle all the wiers and clean up all the mess as well from this giant mess up :(



## 10/26/2025 3 PM - CAD Changes  

Since I realized that the motor count currently doesn't work I fixed it in cad to slot in and hopefully not let the motor spin anymore. I also fixed the pipe that connects to the chute because It was rally thick and the ID was not very big. I have sliced these prints and will start the print later today.





## 10/26/2025 7 PM - Started Wiring  

I got a bunch of the wires criped and pluged in! Criping DuPont is not fun but I am working on getting better. So far I got the frist stepper motor, heater, 12v fan, button, temp sensor and rotory encoder all wired up. As I am doing this I am trying to keep all the wires as tidy as I can so trouble shooting later on is easy. I still need a wire the relays and the fans and motor. All the componets I still need to do run on 5v from the buck thats why I am doing that later.



## 10/27/2025 - Print and finish wiring  

Today I started by slicing everthing that I haven't already printed, then I started the print. When I checked on it in an hour 1 of the prints was going fine the other did not. So I purged the nozzel and cleaned it with come cold pulls and then restarted the print.




I also worked on finishing all the wiering from yesterday, I tried to keep everything clean for de bugging later on. I was able to wire the relays to the RAMPS board and the fans and motor to the relays and the buck. I had to Dupont crimp a few more wiers and like always that was a pain to do. one of these days I will get it. 
THis is what the final thing looks for now. I am going to check everything first tomorrow and then write code and test everything.


## 10/28/2025 - Print clean up and code  

So today the prints were done, so I got them off the build plate cleaned of all the glue from the build plates, cleaned off the prints by removing all supports and the rafts and brims and skirts. I have not tried assembling any of the parts other than the gear for the motor and the hole is too small so I will add that on the list of things to fix in CAD. Since I had all the wiring done I wanted to write some code to test all the components. I first traced every wire to make sure nothing we going to short or anything like that. Then with all the pin numbers I started writing the code. Here is what the code does, the rotary encoder controls the speed of the stepper motor, the button on the encoder toggles which motor speed it controls. The button toggles heating on or off. The fan relay turns on when heating and the vibrator turns on when extruder screw is spinning. Everything works except the relay module for the 2 fans, I think the relay is broken cause the light turns on when high but I don't hear a click. I will have to replace it with a custom diy relay like the other one. I have not tried heating yet but I will do that tomorrow. IN the code the hardest part was the logic for the toggle motor speed and figuring out a naming convention for all the different parts.


https://github.com/APurbiya/DIY_Recycler/commit/f3e4fef83a198f3a0e7130261d2be380f6635ba6

## 10/29/2025 7 AM - Early morning CAD  

I woke up early today so I decided to get some cad done so I can print it later today. I increased the hole diameter of the motor gear and I designed a holder for the motor since it needs to be elevated a little. I have sliced both the models and will start the print in school today



## 10/29/2025 6 PM - Print Clean up, Assembly and Electronics  

I got a whole lot done today, after slicing the parts this morning I was able to start the prints, once the prints were done I got it off the plate cleaned it up. For assembly I got all the printed parts in, the spooler gear and the stepper motor, the shredder trey, the extruder pipe, and even the shredder motor mount. After doing all of this I had to fix the relay. I made a second custom relay module and got it put into the frame and wiered up. Soldering was hard as such a awkward angle. Once I got that done I tested to make sure the fans were running, they were working. I wanted to fix the vibrational motor as it seems to be vibrating too fast. I tried swaping it for a smaller motor but it is not helping, so I need to think of something better. I also did a full heating and cooling test getting the extruder to 300deg c. it took almost 25min to get to that temp, I think the power supply or the ramps board are not powerfull enought but I have to deal with it now. I am almost ready to do my first extrusion just need to get the new fuse and put it in and then run the shredder.





## 10/29/2025 9 PM - Fixing the shredder motor  

Well the fuse came, I replaced it and tested it only to find out the controller is now broken. :( No worries I had a back up plan, I had a button that I was originaly going to use instead of the controller. But unfortunalely I did not plan in my cad for a hole for the button. So I started heating up a screwdriver on the stove and then poking holes in a circle until I could knock out the center and have a hol big enough for the button. Then I soldered some wiers to the motor and the button to make that part of the cuircit work. Once that was working I started testing things like the spooler motor only to find out the pin nums in my code were wrong so I fixed that by looking up the actual pin nums on the ramps documentation and then I realized my max speed was too slow so I increased that as well. I am very close to test this entire thing, I just need something to cover the back and close the front.




## 10/30/2025 6 AM - Sketching for laser  

I want to make panels for the front and back of my project so its fully enclosed. To do that took the original skecth and copied it into a new sketch where I made a few changes of removing the lines and adding a spot for the usb printer cable. I am going to use magnets to attach everything together. 
Since the H2D laser volume is small I split the sketch into 4 parts.

I will prep the laser cutter later today when I generate the paths in bambu suite I also want to add 2 qr codes that lead to the git hub and onshape. I am thinking about cutting the back panel out of wood and the front panel out of some sort of acrylic

## 10/30/2025 6 PM - Laser Cutting + Assembly  

I had the dxf files ready so in school I got the panels ready for cutting. I wanted to used yellow acrylic for the back and clear for the front, turns out that clear doesn't cut well on the H2D somy teacher gave me a hacksaw I got to work. As for the yellow that was super easy and was able to cut it off.I also used a deburring tool to smooth out some of the edges. Then at home I started by pealing the sheets, for some reason on the yellow the film came off really easily almost in one piece, on the clear it just wasn't working and I wanted to get everything off. Since I used the hacksaw on the clear the cuts wern't straight so glueing it was a strugle I got super glue all over my hands and had to resort to using tape. After all 8 pannels were joined I got some magnets to hold the plates up. It doesn't look the best but it looks as good as I could with the technologies I had available to me. I have excluded all times that the laser was running and only included time I working hands on.




PXL_20251031_004117937.MP  

## 10/31/2025 - 1 step farward 4 steps back  

Well, today was a bad day. I wanted to test all the systems including extrusion I started by shredding some of the poop. After some time of doing that the shredder breakes in a really bad way. I am going to need to beef up that part and re print it. With the little that I had broken down I tried extruding. it took a while to heat up after that I started spining the motor and it did not seem to be taking anything down, so I fliped the wiers stuff was moving so I thought it was working turns out it was still spining out the wrong way, so I made a change in the code so if I hold the encoder button it reverses the direction of the motor. Now it was spining the right way but then it did not seem to be extruding so I opened it up this got the filament everywhere, I spun it by hand for some time and I got a little bit of extrusion so I thought it was working so I put it all back together and then again nothing, so now I was really confused. I take it apart again everything seems okay. while trying to feed more scrps in I realized my chute is not angeled enough to let gravity to do its thing so I need to redesign that as well. I think I need to go back to the drawingn board and think about what I am doing wrong. I also had to cut the chute with a dremel because I could not see anything inside.





PXL_20251031_214938171.MP

## 11/1/2025 12 PM - Extruder Re-CAD  

Since my old extruder had some problems I started working fixing the cad so it can work better. My old assembly had 2 27mm m3 stand offs and a 5mm plate and a 3mm plate for a total of 62mm for my new stack I cut some screws heads of so its only the threaded part and linked 2 sand off together 30mm and 27mm and then used a 5mm plate for a total of 62mm. Then I fixed the fan vent angel and size to work with this new design and then I had to redo the chute. I tried some thing completly different this time. While I was working on the chute I sliced and started the print for the 5mm plate it was only 18mins. It took me a while to get the sweep feature in onshape to work the way I wanted it to. Once I was happy with everything I made an assembly to see how everything looks. After that I removed and cleaned up the plate print then I emptied the Vat and cleaned it up to put clear resin in the tank to print the chute. I am printing it in clear so I can see what is going on. I sliced the model and started the print. Once the print was done I got it off the plate and cleaned up. Next I will put the assembly all together. I also beefed up the shredder so it does not crack/explode the next time.







## 11/1/2025 5 PM - Extruder Assembly V4 and testing  

I got the entire extruder put back together with the new part. Now it was time to test it. While the block was heating up I manually cut up some filament into pellet sized chunks the I could put down the chute to test. In around 30mins I had enough pellets and the nozzle had heated that I could start the test. I pull all the pellets in an nothing came out :( I thought this might be due to the slow motor rpm so I let is keep going for a while. When nothing happened I took it apart nothing looked strange but none of the new chucks had made it down. So I removed the chute and started testing I went back a forth with the different directions of rotation to finally realize I might have been running it wrong this entire time. So now after waiting a while it seemed tube working but nothing was coming out so I opened it again looks like I did not wait long enough. So I cleaned everything back up and put everything back together. I also put the vibration motor back on to help with the pellet distribution. Hopefully the next test I do it gives me some good extrusions.






## 11/2/2025 1 PM - It Works! (Kinda)  

I started today of by removing ot jumpers under the stepper driver on the ramps board to get better rmps, but I ended up putting 2 back in. So I have slightly better RPM. 

Then I tried just doing an extrusion so I cut up some filament while the block heated up then I put everything in. I waited a really long time hoping something would come out but nothing came out. So I burned my fingers taking everything apart to look inside to find that not a lot of stuff made it down. 

So I put everything back together and this time I put pellets in there one by one. This is when I realized that the heating cartraige was way too high up it needed to be lower. I moved it down and then ran the test again. This time I changed some of the temps and fans speeds to help. I also made sure the vibrator motor was running the way it should be. I waited a really long time with this set up and nothing seems to be happening but then I saw some stuff was comming out.  So I let it do its thing but then nothing more came out :( So I opened it up again and this was the first time the inside looked the way it should have. So I just didn't wait long enough. I think the vibrator motor should also be on PWM so I can control its speed some how. But I think what I did today was productive. Tommorow I am going to print the shredder parts in school and then I can do a better test hoping for some better results. I think I am headed in the right direction as of right now.

I also made some code changes to make everything safer like blocking the motor from spinning when the temp is too low.

## 11/2/2025 5 PM - Electronics ++  

I wanted to change the relay to a motor driver, so thats exactly what I did, I had to change up a bunch of the wiring to make this work. Also the code did not seems as straight forward as it was. Whatever pin I tried for the Enable pin turned out to be a non PWM pin. Finaly I had the full code working with the new hardware. Now I am ready to run the extruder and see if stuff comes out.



## 11/3/2025 - More tuning  

I started today by watching a few videos and reading some papers to understand and learn about the screw system and if I was doing it correctly. Based on what I found I was doing most things correctly.

https://www.youtube.com/watch?v=BT04glGDjB4
https://www.aniwaa.com/guide/3d-printers/guide-to-pellet-additive-manufacturing/

So after that I decided to drill a 0.8mm nozzel to a size closer to 1.75mm I went with a number 52 drill but which is around 1.60mm which should be good. I did this on the lathe at school because I wanted to make sure the hole was staight. I put the nozzel in the collet and then put the drill in the side stock and then pushed it in. I had to swap the chuck on the lathe from a collet to the self-centering chuck to drill the hole properly. I also used some cutting oil to make sure nothing bad happens and then filed it to make sure it was not sharp.  Then at home I heated the block to 200deg c and then swap the nozzel. Then this time I cut down white filament so I could see the transition. I started feeding it but nothing seemed to be happening for the first 20-30min. I shaked the extruder and then slowly stuff started comming out. It started with thin brown color, then after a long time it became thick and closer to white and then finaly it was looking good. I did have to increase the extruder temp back to a high number closer to 300deg c. I also made some very tiny chnages to some numbers in the code to help tune the extrusion. This is where I ran out of the chopped filament so I had to stop. but I am getting close. Tomorrow I will probably print the shredder and work on that. After I ran out of pellet I took the thing apart to see if everything inside looked okay which now it does.





## 11/4/2025 - Fixing the shredder  

Since I cracked the old shredder and I beefed it up earlier I decided to print it out. So I sliced it and this time I tired something different I tried out some support interface. Once the print was done I removed it and clean up was a pain in the the nut slot, I just crushed out as many supports I could. The next challeneg was getting the motor out I had put it in a way that it would not come out. I had to break a few things and evern ripped one of the wiers out. I put everyuthing back together then soldered the wier back in place. Then the hard part of adjusting the screws on the ruler to get it to cut just right. I spent a good amount of time getting it to shred just right. After that just did some more tests and I should be ready to go back to tuning the extruder.





## 11/5/2025 - Tuning and Testing  

Today, first I put the extruder back together as I left it as is last time I took it apart
 Then I removed one more jumper from the ramps board to get slightly higher rpm as last time I was just maxing it out. . Once I got everything put back together I was ready to start testing.  I was hoping to see some better extrusions today so I had dried out the filament over night. as the block heated up I chopped up the filament. And then Started extruding. Fot this test I want to finish everything I put into the chute so it took longer. at first it looked like it was pooping out little drops and after that I did getting some more consistent extrusions. Sadly I emptied the entire top and only got this much. I think the next test I do I want to run some of the shredded filament and I also need to reduce the temp becuase it looks like the filament it buring up.


I am headed in the right direction just need to keep going. During the test I did have thermal runaway twice so I need to figure out a way to fix that issue, and maybe add some idicator LEDs. I also noticed that the stepper motor was getting really hot and had to monitor that closly, maybe a heat sink on the stepper motor will help.

## 11/6/2025 - Mainly Code  

Today I worked a lot on the code and getting it to the point where its easy to yuse for anyone. I moved the important variables to the top and fixing the values I talked about in the last journal. I also made a change to have different max speeds for the different motors as they have different number of jumpers attached to them. When I wanted to take a break from fixing code I added some magnets to the funnel on top of the shredder to make shredding easier. I had to remove the magnets from a previous project. I soaked it in IPA to remove it and then I made holes in the both the parts using a old soldering iron and then glueing the magnets in. After the glue dired I realized if put the magnets facing the wrong way so they didn't stick so I had to remove one of the magnets and stick it back. After that I sanded the parts a little so they sit flat. I also did a lot of research to figure out when PLA burns and how I can avoid it. So the new temps should not let it burn. Just to make sure I heated the heat block on my og ender to that temp and extruded very slow to make sure these numbers are good.





## 11/7/2025 - Full Systems Test :(  

I wanted to run a fut test from start to finish. I started by gabbing some of the Bambu poop and shredding it up. I ran it through almost 10-15 times to get it small enough to what I likeded. I also tried pelatizing some filament but that did not go so well. Then The heater was heated up so I put everything in and started trying to extrude.


After debugging the heat faliur for a while I realized it was not going to extrude anything so I opened the 250 deg c block (burned my hand doing so) to see what happened, looked like a clog so I cleaned it up put everything back together and tried to run the test again.
 This time when I ran the test nothing came out even after waiting a really long time so I opened the block again :( and saw something better
 I am thinking it did not get hot enought or something like that. I did not put everything back together cause I realized 2 of the plates got so how they started warping, so I need to reprint them and assembel the whole thing again


## 11/8/2025 - Some hardware Some software  

Today I started by slicing and printing the 2 plates that hold the extruder in place. Once Printed I cleaned up the prints with IPA and then cured them before putting the whole extruder assembly back together. I had to hold glue the fans in place as well. 



Then I fixed the magnets that hold up the panel as they were falling off, I had to measure mark and glue to get everything just right. I had to pull some more magnets out from the project to get the magnets I needed. I also messed up some of the poles of the magents and had to rip them off to flip it. At the end I ended up with super glue all over my fingers :(





Then I conected an esp 32 to the tx rx pins of the ramps so I can print everything on a webpage


After this I started wiriting code. I did not have to change anything on the arduino side as it was already printing the data. But I realized this too late I was messing with the code to make a second serial to send it to that. But after restoring the original code I read a few articles and started writing the code. Then when I started hiting road blocks I asked GPT, but that code took almost 15 mins to compile so I knew something was wrong so I read more articles and got it working. I got the IP adress put it in my browser got the code to load
 But it was printing BS so I did more searching and turns out the esp wasnt 3.3v on tx rx but the ramps runs on 5v so I don't think this will work. I am going to upload the code on github but it does not work.

## 11/9/2025 - Ground Work Before final test  

Lots of cad work got done today! I was just prcastinating from running any more tests. Instead of giving them to you in sentences here is a short list



The stepper motor sticks out because I could not find one of the right size after looking for a long time on grab cad.

Designed
Back Panel
Front Pannel
Completed
Main Assembly
Extruder Assembly
Added Stepper Motors
Added planatery gear box
Did some Misc fixes in CAD like fixing and solving a few errors and dimensioning everything and contraining it to the assembly so if someone wanted they could use the cad as a assembly guide. I am still going to make a full assembly guide but this will have to do for now.

Then I moved on to update the BOM to have everything I have used so far. I had to add a whole lot of parts that I did not think I would need at first but then ended up using.


I am also updating the banner photo!

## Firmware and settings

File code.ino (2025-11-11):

// ====== USER SETTINGS ======
const uint8_t VIB_SPEED_PERCENT = 80;    // 0..100% (set 100 for full power)
// ================== Temperature & safety ==================
float EXTRUDER_MIN_C = 240.0f;          // start heating below this
float EXTRUDER_MAX_C = 260.0f;          // stop heating at/above this
const float COOL_RELAYFAN_OFF_C = 120.0f;
const float MAX_SAFE_C = 300.0f;        // keep below 300
const float MIN_EXTRUDE_C = 160.0f;     // E0 won't spin below this

// Fan PWM levels
const uint8_t FAN12_IDLE_PWM   = (uint8_t)(0.15 * 255); // 15%
const uint8_t FAN12_ACTIVE_PWM = (uint8_t)(0.45 * 255); // 20%

const float MAX_E0_SPS = 2300.0f;  // <-- Extruder cap //only 1 jumper
const float MAX_E1_SPS = 4150.0f;  // <-- Spooler cap


// Bambu Poop → Filament: RAMPS 1.4 Extruder/Spooler + Heater + Fans + Vibrator
// Board: Arduino MEGA 2560 + RAMPS 1.4
// Version: v0.3 (pin fixes, safety latch, MOSFET stuck-on guard, tidy comments)
// Notes:
// - This sketch drives two steppers (E0=Extruder on RAMPS X driver, E1=Spooler on RAMPS Y driver),
// E0 heater MOSFET (D10) + T0 thermistor (A13), 12V PWM fan (D9), two 5V fan pins,
// and a small DC vibrator motor (via H-bridge) that tracks E0 motion.
// - Encoder short press: switch active motor (E0/E1). Long press (>700ms): reverse dir of active motor.
// - Heat button toggles heater request. E0 only turns when hot enough.
// - Added: pin conflict fixes, hard FAULT latch (requires power cycle),
// stuck‑on MOSFET guard, compile-time pin collision checks.
//
// *********** WIRING (RAMPS 1.4 assumed) ***********
// * STEPPERS (use X/Y drivers for easier pins; rename if you actually use E0/E1 slots)
// - E0 (Extruder) -> RAMPS X driver socket (A_* pins below map to X_* pins on RAMPS)
// A_STEP_PIN = 54 (X_STEP = A0)
// A_DIR_PIN = 55 (X_DIR = A1)
// A_ENABLE = 38 (X_EN)
// - E1 (Spooler) -> RAMPS Y driver socket (B_* pins below map to Y_* pins on RAMPS)
// B_STEP_PIN = 60 (Y_STEP = A6)
// B_DIR_PIN = 61 (Y_DIR = A7)
// B_ENABLE = 56 (Y_EN)
// * HEATER/TEMP
// HEATER_PIN = D10 (RAMPS E0 MOSFET)
// THERMISTOR_PIN = A13 (RAMPS T0)
// * FANS
// FAN12_PWM_PIN = D9 (RAMPS 12V Fan MOSFET, PWM)
// FAN5V_1_PIN = D4 (AUX/SERVO header; 5V logic → drive external 5V MOSFET or small fan)
// FAN5V_2_PIN = D6 (moved off D5 to avoid conflict; also on SERVO header)
// * VIBRATOR (small DC motor via L298N/L9110S etc.)
// VIB_MOTOR_A = D16 (IN1)
// VIB_MOTOR_B = D17 (IN2)
// VIB_MOTOR_EN = D5 (PWM ENA) <-- ensure no physical conflict with FAN pins
// * RELAYS (active‑HIGH, NO contacts)
// RELAY_VIBRATOR_PIN = D18 (indicator/compat; mirrors E0 motion)
// RELAY_FAN_PIN = D15 (latch on when heating until < COOL_RELAYFAN_OFF_C)
// * CONTROLS
// HEAT_BUTTON_PIN = A15 (active‑LOW momentary)
// ENC_CLK=D31, ENC_DT=D33, ENC_SW=D35
// ****************************************************


// ====== RAMPS pins ======
#define A_STEP_PIN    54   // E0 STEP
#define A_DIR_PIN     55   // E0 DIR
#define A_ENABLE_PIN  38   // E0 ENABLE

// E1 stepper
#define B_STEP_PIN    60   // E1 STEP
#define B_DIR_PIN     61   // E1 DIR
#define B_ENABLE_PIN  56   // E1 EN

// Heater & sensor
#define HEATER_PIN      10        // D10 = E0 heater MOSFET
#define THERMISTOR_PIN  A13       // T0 input (to GND + A13)

// Fans
#define FAN5V_1_PIN   4
#define FAN5V_2_PIN   5
#define FAN12_PWM_PIN 9           // D9 = 12V fan MOSFET (PWM)

// Relays (normally open → active-HIGH)
#define RELAY_VIBRATOR_PIN 18     // kept as indicator/compat; follows E0 motion
#define RELAY_FAN_PIN       15    // ON when heating (latched until <cool temp)

// Buttons / Encoder
#define HEAT_BUTTON_PIN A15
#define ENC_CLK 31
#define ENC_DT  33
#define ENC_SW  35

// Vibrator motor driver pins (H-bridge / L298N-style)
#define VIB_MOTOR_A 16            // IN1 (direction A)
#define VIB_MOTOR_B 17            // IN2 (direction B)
#define VIB_MOTOR_EN 5            // ENA (PWM speed control)

// Relay logic for NO type (HIGH = ON)
#define RELAY_ON  HIGH
#define RELAY_OFF LOW

// Thermistor model (100k NTC, B3950, 4.7k pull-up)
const float R_SERIES = 4700.0f;
const float R0 = 100000.0f;
const float T0_K = 273.15f + 25.0f;
const float BETA = 3950.0f;
const unsigned long READ_INTERVAL_MS = 200;

// Simple thermal-runaway guard
const float TR_MIN_RISE_C = 1.0f;         // must rise at least this much
const unsigned long TR_WINDOW_MS = 20000; // within 20s of heater turning on

// ================== Stepper control ==================
volatile long encValue = 0;
int activeMotor = 0; // 0 = E0, 1 = E1
int lastClk = HIGH;

// Target speed (steps/sec) adjusted by encoder; actual speed slews toward target
float targetE0_sps = 0;
float targetE1_sps = 0;
float speedE0_sps  = 0;
float speedE1_sps  = 0;

// Accel (slew) parameters
const float SPS_MIN  = 0.0f;
// NOTE: replaced single max with per-motor maxes:
const float ACCEL_SPS_PER_S = 8000.0f;   // how fast we ramp (steps/s per second)

// Step timing
unsigned long nextStepE0_us = 0;
unsigned long nextStepE1_us = 0;
bool stepStateE0 = false;
bool stepStateE1 = false;

// Direction flags + helper
bool dirE0_forward = true;
bool dirE1_forward = true;
inline void applyDirPins() {
  digitalWrite(A_DIR_PIN, dirE0_forward ? HIGH : LOW);
  digitalWrite(B_DIR_PIN, dirE1_forward ? HIGH : LOW);
}

// ================== State ==================
unsigned long lastReadMs = 0;
bool heaterOn = false;
bool heatRequested = false;
bool relayFanLatched = false;
float lastTempC = 25;
bool extrudeTempOK = false;  // E0 motion allowed only if true

// Runaway guard tracking
bool tr_armed = false;
unsigned long tr_start_ms = 0;
float tr_start_temp = 0;

// ===== Helper: map 0..100% to 0..255 PWM =====
inline uint8_t pctToPwm(uint8_t pct) {
  if (pct > 100) pct = 100;
  return (uint8_t)((pct * 255UL) / 100UL);
}
const uint8_t VIB_PWM = pctToPwm(VIB_SPEED_PERCENT);

// ================== Debounce helpers ==================
bool readButtonDebounced(uint8_t pin) {
  static unsigned long tLast = 0;
  static uint8_t last = HIGH, stable = HIGH;
  uint8_t r = digitalRead(pin);
  if (r != last) { tLast = millis(); last = r; }
  if (millis() - tLast > 25) stable = r;
  return (stable == LOW);
}

// ================== Thermistor ==================
float readThermistorC() {
  int a = analogRead(THERMISTOR_PIN);
  if (a <= 1)    return -9999.0f;  // short to GND
  if (a >= 1022) return  9999.0f;  // open circuit
  float Rt = R_SERIES * ((float)a / (1023.0f - (float)a));
  float invT = (1.0f / T0_K) + (1.0f / BETA) * log(Rt / R0);
  return (1.0f / invT) - 273.15f;
}

// ================== Encoder ==================
// Short press: toggle which motor to control
// Long press (>700ms): reverse direction of active motor
void handleEncoder() {
  // quadrature
  int clkState = digitalRead(ENC_CLK);
  if (clkState != lastClk) {
    if (digitalRead(ENC_DT) != clkState) encValue++; else encValue--;
    if (activeMotor == 0) {
      // --- cap E0 target at 2400 sps ---
      targetE0_sps = constrain(targetE0_sps + (encValue > 0 ? 50 : -50), SPS_MIN, MAX_E0_SPS);
    } else {
      // --- cap E1 target at 6000 sps ---
      targetE1_sps = constrain(targetE1_sps + (encValue > 0 ? 50 : -50), SPS_MIN, MAX_E1_SPS);
    }
    encValue = 0;
  }
  lastClk = clkState;

  // SW short/long press
  static bool swLatch = false;
  static unsigned long pressStart = 0;
  bool pressed = (digitalRead(ENC_SW) == LOW);

  if (pressed && !swLatch) { swLatch = true; pressStart = millis(); }
  if (!pressed && swLatch) {
    unsigned long held = millis() - pressStart;
    swLatch = false;
    if (held >= 700) {
      // flip direction on active motor
      if (activeMotor == 0) dirE0_forward = !dirE0_forward;
      else                  dirE1_forward = !dirE1_forward;
      applyDirPins();
      Serial.print("Dir E"); Serial.print(activeMotor);
      Serial.print(" -> ");  Serial.println((activeMotor==0?dirE0_forward:dirE1_forward) ? "FWD" : "REV");
    } else {
      // toggle which motor is controlled
      activeMotor = 1 - activeMotor;
      Serial.print("Active motor -> E"); Serial.println(activeMotor);
    }
  }
}

// Slew actual speeds toward target for gentle accel/decel
void updateSpeedSlew() {
  static unsigned long last_us = micros();
  unsigned long now = micros();
  float dt = (now - last_us) / 1000000.0f;
  last_us = now;

  float maxDelta = ACCEL_SPS_PER_S * dt;

  // E0
  float delta0 = targetE0_sps - speedE0_sps;
  if (delta0 >  maxDelta) delta0 =  maxDelta;
  if (delta0 < -maxDelta) delta0 = -maxDelta;
  speedE0_sps += delta0;
  // enforce cap
  if (speedE0_sps > MAX_E0_SPS) speedE0_sps = MAX_E0_SPS;
  if (speedE0_sps < SPS_MIN)    speedE0_sps = 0;

  // E1
  float delta1 = targetE1_sps - speedE1_sps;
  if (delta1 >  maxDelta) delta1 =  maxDelta;
  if (delta1 < -maxDelta) delta1 = -maxDelta;
  speedE1_sps += delta1;
  // enforce cap
  if (speedE1_sps > MAX_E1_SPS) speedE1_sps = MAX_E1_SPS;
  if (speedE1_sps < SPS_MIN)    speedE1_sps = 0;
}

// Service both steppers (non-blocking)
void serviceSteppers() {
  applyDirPins();   // keep pins synced with flags
  unsigned long now = micros();

  // --- E0 (gated by temperature) ---
  float e0_run_sps = extrudeTempOK ? speedE0_sps : 0.0f;

  if (e0_run_sps > 1.0f) {
    digitalWrite(A_ENABLE_PIN, LOW);
    unsigned long interval = (unsigned long)(1000000.0f / e0_run_sps / 2.0f);
    if (now >= nextStepE0_us) {
      stepStateE0 = !stepStateE0;
      digitalWrite(A_STEP_PIN, stepStateE0);
      nextStepE0_us = now + interval;
    }
  } else {
    digitalWrite(A_ENABLE_PIN, HIGH);
    digitalWrite(A_STEP_PIN, LOW);
  }

  // --- E1 (always allowed) ---
  if (speedE1_sps > 1.0f) {
    digitalWrite(B_ENABLE_PIN, LOW);
    unsigned long interval = (unsigned long)(1000000.0f / speedE1_sps / 2.0f);
    if (now >= nextStepE1_us) {
      stepStateE1 = !stepStateE1;
      digitalWrite(B_STEP_PIN, stepStateE1);
      nextStepE1_us = now + interval;
    }
  } else {
    digitalWrite(B_ENABLE_PIN, HIGH);
    digitalWrite(B_STEP_PIN, LOW);
  }
}

// ================== Setup ==================
void setup() {
  Serial.begin(115200);

  // Steppers
  pinMode(A_STEP_PIN, OUTPUT);
  pinMode(A_DIR_PIN, OUTPUT);    digitalWrite(A_DIR_PIN, HIGH);
  pinMode(A_ENABLE_PIN, OUTPUT); digitalWrite(A_ENABLE_PIN, HIGH);

  pinMode(B_STEP_PIN, OUTPUT);
  pinMode(B_DIR_PIN, OUTPUT);    digitalWrite(B_DIR_PIN, HIGH);
  pinMode(B_ENABLE_PIN, OUTPUT); digitalWrite(B_ENABLE_PIN, HIGH);

  // Heater & fans
  pinMode(HEATER_PIN, OUTPUT);         digitalWrite(HEATER_PIN, LOW);
  pinMode(FAN5V_1_PIN, OUTPUT);        digitalWrite(FAN5V_1_PIN, LOW);
  pinMode(FAN5V_2_PIN, OUTPUT);        digitalWrite(FAN5V_2_PIN, LOW);
  pinMode(FAN12_PWM_PIN, OUTPUT);      analogWrite(FAN12_PWM_PIN, 0);

  // Relays
  pinMode(RELAY_VIBRATOR_PIN, OUTPUT); digitalWrite(RELAY_VIBRATOR_PIN, RELAY_OFF);
  pinMode(RELAY_FAN_PIN, OUTPUT);      digitalWrite(RELAY_FAN_PIN, RELAY_OFF);

  // Vibrator motor driver
  pinMode(VIB_MOTOR_A, OUTPUT);
  pinMode(VIB_MOTOR_B, OUTPUT);
  pinMode(VIB_MOTOR_EN, OUTPUT);
  analogWrite(VIB_MOTOR_EN, 0);
  digitalWrite(VIB_MOTOR_A, LOW);
  digitalWrite(VIB_MOTOR_B, LOW);

  // Buttons / Encoder
  pinMode(HEAT_BUTTON_PIN, INPUT_PULLUP);
  pinMode(ENC_CLK, INPUT_PULLUP);
  pinMode(ENC_DT,  INPUT_PULLUP);
  pinMode(ENC_SW,  INPUT_PULLUP);

  analogReference(DEFAULT);
  delay(50);
  lastReadMs = millis();

  Serial.println("Ready. Max E0=2400 sps, E1=6000 sps. HEAT toggles heating. Encoder SW short=select motor, long=reverse dir. E0 gated <160C.");
}

// ================== Loop ==================
void loop() {
  handleEncoder();
  updateSpeedSlew();
  serviceSteppers();

  // Heat button toggle (debounced)
  static bool heatBtnLatched = false;
  bool heatBtn = readButtonDebounced(HEAT_BUTTON_PIN);
  if (heatBtn && !heatBtnLatched) {
    heatBtnLatched = true;
    heatRequested = !heatRequested;
    if (heatRequested) tr_armed = false; // will arm when heater actually turns on
    Serial.print("Heat request -> "); Serial.println(heatRequested ? "ON" : "OFF");
  } else if (!heatBtn) heatBtnLatched = false;

  // Temperature & heater control
  unsigned long nowms = millis();
  if (nowms - lastReadMs >= READ_INTERVAL_MS) {
    lastReadMs = nowms;
    lastTempC = readThermistorC();

    bool fault = (lastTempC > MAX_SAFE_C || lastTempC == 9999.0f || lastTempC == -9999.0f);
    if (fault) {
      heaterOn = false;
      heatRequested = false;
      relayFanLatched = true; // keep cooling
      Serial.println("TEMP FAULT: heater forced OFF");
    } else {
      if (heatRequested) {
        if (lastTempC < EXTRUDER_MIN_C) {
          if (!heaterOn) {
            tr_armed = true;
            tr_start_ms = nowms;
            tr_start_temp = lastTempC;
          }
          heaterOn = true;
        } else if (lastTempC >= EXTRUDER_MAX_C) {
          heaterOn = false;
        }
      } else {
        heaterOn = false;
      }
    }

    // Thermal-runaway check
    if (heaterOn && tr_armed) {
      if (nowms - tr_start_ms > TR_WINDOW_MS) {
        if ((lastTempC - tr_start_temp) < TR_MIN_RISE_C) {
          heaterOn = false;
          heatRequested = false;
          Serial.println("RUNAWAY GUARD: insufficient temp rise, heater OFF");
        } else {
          tr_armed = false; // passed this window
        }
      }
    }

    // Apply heater MOSFET
    digitalWrite(HEATER_PIN, heaterOn ? HIGH : LOW);

    // Update extruder temp gate
    extrudeTempOK = (lastTempC >= MIN_EXTRUDE_C);

    // Determine motion states
    bool e0ActuallySpinning = (extrudeTempOK ? speedE0_sps : 0.0f) > 1.0f;
    bool anySpin = e0ActuallySpinning || (speedE1_sps > 1.0f);

    // 12V fan PWM: 20% if heating or spinning; else 15%
    uint8_t pwm12 = (heaterOn || anySpin) ? FAN12_ACTIVE_PWM : FAN12_IDLE_PWM;
    analogWrite(FAN12_PWM_PIN, pwm12);

    // Relay FAN logic (latched until cool)
    if (heatRequested || heaterOn) relayFanLatched = true;
    if (!heatRequested && !heaterOn && lastTempC < COOL_RELAYFAN_OFF_C) relayFanLatched = false;
    digitalWrite(RELAY_FAN_PIN, relayFanLatched ? RELAY_ON : RELAY_OFF);

    // Relay VIBRATOR (indicator/compat): follows E0 actual motion
    digitalWrite(RELAY_VIBRATOR_PIN, e0ActuallySpinning ? RELAY_ON : RELAY_OFF);

    // ==== Vibrator motor driver follows E0 only ====
    if (e0ActuallySpinning) {
      digitalWrite(VIB_MOTOR_A, HIGH);
      digitalWrite(VIB_MOTOR_B, LOW);
      analogWrite(VIB_MOTOR_EN, VIB_PWM);
    } else {
      analogWrite(VIB_MOTOR_EN, 0);
      digitalWrite(VIB_MOTOR_A, LOW);
      digitalWrite(VIB_MOTOR_B, LOW);
    }

    // 5V fans follow actual heater state
    digitalWrite(FAN5V_1_PIN, heaterOn ? HIGH : LOW);
    digitalWrite(FAN5V_2_PIN, heaterOn ? HIGH : LOW);

    // Debug
    Serial.print("T="); Serial.print(lastTempC, 1);
    Serial.print(" | heatReq="); Serial.print(heatRequested);
    Serial.print(" | heaterOn="); Serial.print(heaterOn);
    Serial.print(" | GateE0="); Serial.print(extrudeTempOK ? "OK" : "COLD");
    Serial.print(" | E0="); Serial.print(speedE0_sps, 0);
    Serial.print(" | E1="); Serial.print(speedE1_sps, 0);
    Serial.print(" | Vib(E0)="); Serial.print(e0ActuallySpinning ? "ON" : "OFF");
    Serial.print(" | PWM12="); Serial.println(pwm12);
  }
}

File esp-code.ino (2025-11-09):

#include <WiFi.h>
#include <WebServer.h>

// ===== Wi-Fi =====
const char* ssid     = "**********";
const char* password = "*************";

// Use ESP32 Serial2 on GPIO16 (RX2) / GPIO17 (TX2)
// Match Mega baud (your Mega prints at 115200)
#define ESP32_RX2 16
#define ESP32_TX2 17
const uint32_t MEGA_BAUD = 115200;

// ===== Web server =====
WebServer server(80);

// ===== Log ring buffer =====
static const size_t MAX_LINES = 200;
String logBuf[MAX_LINES];
size_t head = 0;      // next write index
size_t countLines = 0; // number of valid lines

String pending; // accumulates chars until '\n'

// Append a line into circular buffer
void pushLine(const String& line) {
  logBuf[head] = line;
  head = (head + 1) % MAX_LINES;
  if (countLines < MAX_LINES) countLines++;
}

// Build all lines in chronological order (oldest → newest)
String dumpAll() {
  String out;
  out.reserve(8192);
  size_t start = (countLines == MAX_LINES) ? head : 0;
  size_t n = countLines;
  for (size_t i = 0; i < n; ++i) {
    size_t idx = (start + i) % MAX_LINES;
    out += logBuf[idx];
    if (!out.endsWith("\n")) out += "\n";
  }
  return out;
}

const char* INDEX_HTML = R"HTML(
<!doctype html>
<html>
<head>
  <meta charset="utf-8" />
  <title>Mega Telemetry</title>
  <meta name="viewport" content="width=device-width, initial-scale=1" />
  <style>
    body { font-family: system-ui, -apple-system, Segoe UI, Roboto, sans-serif; margin: 0; }
    header { padding: 12px 16px; background:#111; color:#fff; }
    main { padding: 12px 16px; }
    .card { border:1px solid #ddd; border-radius:12px; padding:12px; max-width:900px; margin:auto; }
    #log { white-space: pre-wrap; font-family: ui-monospace, Menlo, Consolas, monospace; font-size: 13px; max-height: 70vh; overflow:auto; }
    .row { display:flex; gap:8px; align-items:center; margin-bottom:8px; }
    button { padding:8px 12px; border:1px solid #ccc; border-radius:8px; background:#f5f5f5; cursor:pointer; }
    button:hover { background:#eee; }
    .pill { display:inline-block; padding:2px 8px; border-radius:999px; background:#e5e7eb; font-size:12px; }
  </style>
</head>
<body>
  <header>
    <strong>ESP32 Web Dashboard</strong>
  </header>
  <main>
    <div class="card">
      <div class="row">
        <span class="pill" id="status">connecting…</span>
        <button onclick="clearLog()">Clear</button>
      </div>
      <div id="log"></div>
    </div>
  </main>
<script>
let logEl = document.getElementById('log');
let statusEl = document.getElementById('status');
let autoscroll = true;

// Auto-scroll if user is at bottom
function maybeAutoScroll() {
  if (!autoscroll) return;
  logEl.scrollTop = logEl.scrollHeight;
}
logEl.addEventListener('scroll', () => {
  const nearBottom = (logEl.scrollHeight - logEl.scrollTop - logEl.clientHeight) < 40;
  autoscroll = nearBottom;
});

function clearLog() {
  fetch('/clear', {method: 'POST'}).then(r => r.text()).then(t => {
    logEl.textContent = '';
  });
}

async function poll() {
  try {
    const r = await fetch('/logs');
    if (!r.ok) throw new Error('HTTP '+r.status);
    const text = await r.text();
    logEl.textContent = text;
    statusEl.textContent = 'live';
    maybeAutoScroll();
  } catch (e) {
    statusEl.textContent = 'disconnected';
  } finally {
    setTimeout(poll, 1000);
  }
}
poll();
</script>
</body>
</html>
)HTML";

void handleRoot() {
  server.send(200, "text/html; charset=utf-8", INDEX_HTML);
}
void handleLogs() {
  server.send(200, "text/plain; charset=utf-8", dumpAll());
}
void handleClear() {
  countLines = 0; head = 0; pending = "";
  server.send(200, "text/plain", "cleared");
}

void setup() {
  // Optional USB serial for debug
  Serial.begin(115200);
  delay(200);

  // UART from Mega on Serial2 (GPIO16=RX, GPIO17=TX)
  Serial2.begin(MEGA_BAUD, SERIAL_8N1, ESP32_RX2, ESP32_TX2);

  WiFi.mode(WIFI_STA);
  WiFi.begin(ssid, password);
  Serial.printf("WiFi connecting to %s", ssid);
  while (WiFi.status() != WL_CONNECTED) {
    delay(400); Serial.print(".");
  }
  Serial.printf("\nWiFi OK: %s  IP: %s\n", WiFi.SSID().c_str(), WiFi.localIP().toString().c_str());

  server.on("/", HTTP_GET, handleRoot);
  server.on("/logs", HTTP_GET, handleLogs);
  server.on("/clear", HTTP_POST, handleClear);
  server.begin();
  Serial.println("HTTP server started on http://" + WiFi.localIP().toString());
}

void loop() {
  // Pump web server
  server.handleClient();

  // Pull bytes from Mega (via Serial2), accumulate lines
  while (Serial2.available()) {
    char c = (char)Serial2.read();
    if (c == '\r') continue; // normalize
    if (c == '\n') {
      if (pending.length() > 0) {
        pushLine(pending);
        pending = "";
      } else {
        // blank line, still record for spacing
        pushLine("");
      }
    } else {
      // guard against runaway lines
      if (pending.length() < 512) pending += c;
      else { /* drop overly long line */ }
    }
  }
}

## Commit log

2025-10-18 BOM file
    [Recycler BOM.xlsx]
2025-10-18 changed formating and added items
    [Recycler BOM.xlsx]
2025-10-18 Shredder CAD files
    [Shredder - Part 1.step, Shredder - Spur gear (10 teeth).step, Shredder - Spur gear (63 teeth).step]
2025-10-18 main frame v1
    [main-frame.step]
2025-10-19 extruder parts
    [extruder_plates.step, fan mount.step, pellet-chute.step]
2025-10-19 Update for the drill instead of 775
    [main-frame.step]
2025-10-20 Delete CAD directory
    organizing all the cad files
    [Shredder - Part 1.step, Shredder - Spur gear (10 teeth).step, Shredder - Spur gear (63 teeth).step]
2025-10-20 Delete CAD directory
    organizing, new replace files coming in a min
    [extruder_plates.step, fan mount.step, main-frame.step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]
2025-10-20 all step files so far
    I had to delet the old ones as they were not organized, some parts for updated some have stayed the same
    [Shredder - p1.step, extruder - chute.step, extruder Copy 1 - Part 1.step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]
2025-10-21 pipe cad
    [extruder - pipe.step]
2025-10-21 updates joints on the spooler mechanizms
    [main - Spur gear (170 teeth).step, spooler - Part 1.step]
2025-10-22 updated to hold motor and gearbox
    [main - Part 1.step]
2025-10-22 the slot for the motor relected in assembly
2025-10-22 the motor bracket + 4 split
    [main - Motor.step, main - Part 6.step, main - Part 7.step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]
2025-10-26 updated pipe
    [extruder - pipe.step]
2025-10-29 hole bigger and motor holder for spooler
    [main - Spur gear (30 teeth).step, main - motor-holder.step]
2025-10-30 all laser sketches
    [Part Studio 3 - bottom-left.dxf, Part Studio 3 - bottom-right.dxf, Part Studio 3 - top-left.dxf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]
2025-11-01 motor reverse code
2025-11-01 Extruder Re-CAD
    [Shredder - p1.step, extruder - chute.step, extruder Copy 1 - Part 1.step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]
2025-11-02 almost there!
    blocking the motor from spinning when the temp is too low, temp and fan speed changes
    [code.ino]
2025-11-03 Update code.ino
    Vibrator motor PWM
    [code.ino]
2025-11-09 Create esp-code.ino DOES NOT WORK!!!
    DOES NOT WORK!!!
    [esp-code.ino]
2025-11-10 lots of cad changes
    Designed
    Back Panel
    Front Pannel
    Completed
    Main Assembly
    Extruder Assembly
    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
    [HLTNC FLE42-LSW.stp, Stepper motor SUPER POWER.STEP, main - motor-holder.step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]
2025-11-10 updated BOM
    [Recycler BOM.xlsx]
2025-11-11 Update code.ino fan speed increase
2025-11-11 motor speed update
2025-11-11 images for assembly guide
2025-11-12 all the images for assembly
